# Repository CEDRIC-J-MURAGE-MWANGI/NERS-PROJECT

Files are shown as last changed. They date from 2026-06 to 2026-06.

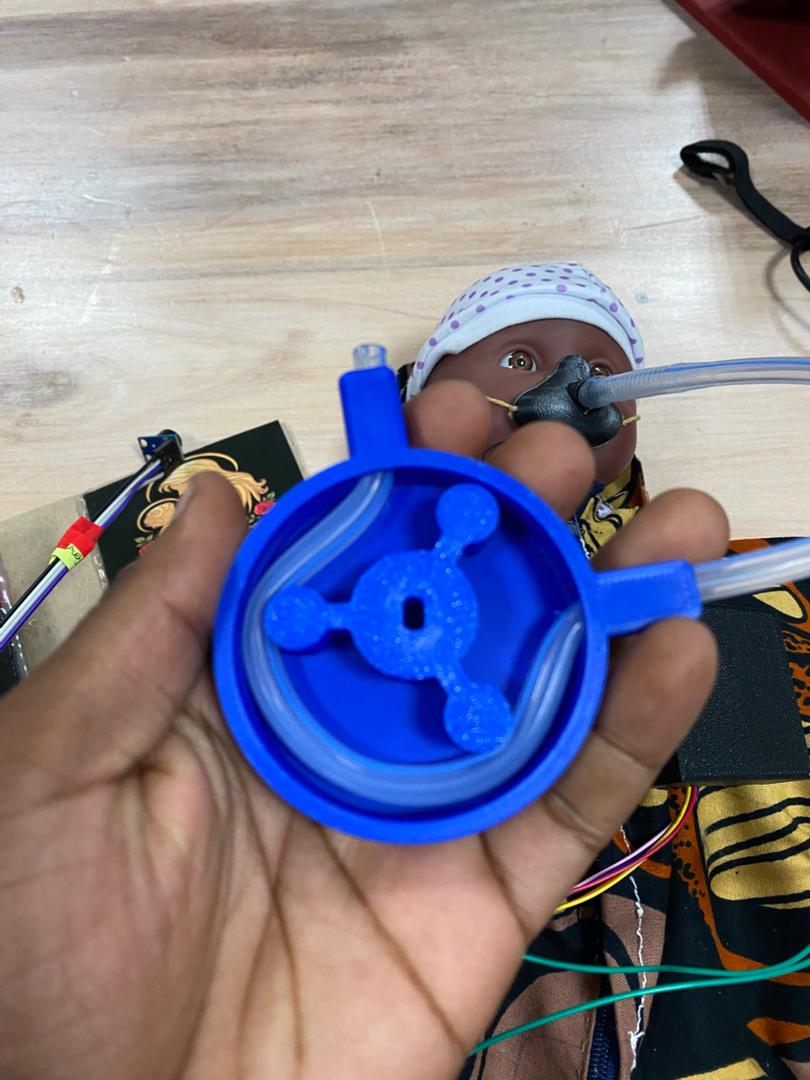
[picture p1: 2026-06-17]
IMAGES/PERISTALTIC PUMP.jpeg

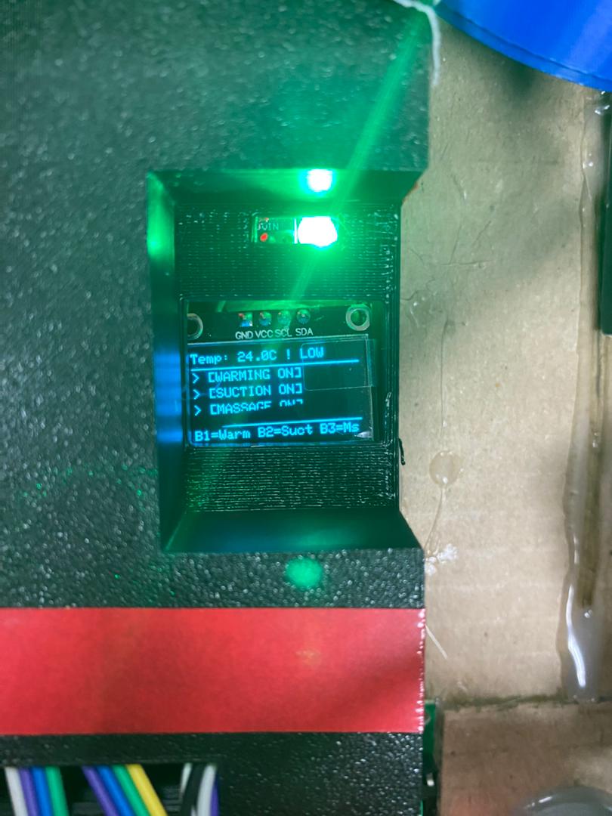
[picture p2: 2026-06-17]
IMAGES/OLED STATUS DISPLAY.jpeg

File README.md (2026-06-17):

# NERS — Neonatal Emergency Response Swaddle

**An integrated, low-cost device for newborn resuscitation in low-resource health facilities.**

> Birth asphyxia is the leading cause of neonatal mortality in Kenya, responsible for 31.6% of all newborn deaths. In the "Golden Minute" after birth, every 30-second delay in starting ventilation raises mortality risk by 16%. NERS exists to remove the delays caused by fragmented equipment during that minute.





---

## Table of Contents
- [Overview](#overview)
- [The Problem](#the-problem)
- [How NERS Works](#how-ners-works)
- [Hardware](#hardware)
- [Firmware](#firmware)
- [Bill of Materials](#bill-of-materials)
- [Results](#results)
- [Repository Structure](#repository-structure)
- [Limitations & Future Work](#limitations--future-work)
- [Team](#team)
- [Acknowledgments](#acknowledgments)
- [References](#references)

---

## Overview

The **Neonatal Emergency Response Swaddle (NERS)** is a single, wearable device that delivers three critical newborn resuscitation interventions simultaneously the moment a non-breathing infant is wrapped in it:

1. **Thermal regulation** — non-contact temperature sensing with embedded warming
2. **Airway clearance** — automated peristaltic suction
3. **Chest stimulation** — rhythmic, bilateral compression

All three modes are independently controlled by an **Arduino Nano V3.0**, activated via labelled push buttons, and monitored in real time on an OLED display. The goal is to eliminate the device-to-device transition time that currently costs lives in under-resourced delivery rooms.

This project was developed through the **Medical Device Innovation Summer Program** at Kenyatta University's **Centre for Design, Innovation & Engineering (CDIE)** lab, in partnership with **Rice 360° Institute for Global Health Technologies**, following a clinical immersion at **Thika Level 5 Hospital**, Kiambu County, Kenya.

A working prototype has been built and validated on a neonatal mannequin, with a total bill of materials cost of **KES 5,937 (~USD 46)**.

## The Problem

In most Kenyan public health facilities, a single birth attendant must manage three separate resuscitation tasks — thermal regulation, airway clearance, and chest stimulation — using three separate, non-integrated pieces of equipment, under acute time pressure and often with limited staff. Each transition between devices costs precious seconds within the Golden Minute.

Key figures motivating this project:
- ~31,000 neonatal deaths in Kenya in 2024 (20.7 per 1,000 live births)
- 16% increase in mortality risk for every 30-second delay in initiating ventilation
- 17.5% of Kenyan neonatal admissions arrive hypothermic, a state linked to a 35% increase in odds of death
- Only 32.7% of Kenyan newborns receive all recommended components of quality neonatal care after birth

NERS targets the fragmentation and operator-dependency at the root of these delays.

## How NERS Works

| Subsystem | Function | Core Components |
|---|---|---|
| **Thermal Regulation** | Continuous non-contact monitoring of neonatal surface temperature with embedded warming | MLX90614ESF IR sensor + heating strip |
| **Airway Clearance** | Controlled negative-pressure suction to clear the airway | 28BYJ-48 stepper motor in a peristaltic pump configuration + silicone tubing |
| **Chest Stimulation** | Rhythmic, bilateral compression replicating the two-thumb encircling technique | Two counter-rotating 28BYJ-48 stepper motors + padded compression elements |
| **Control & Feedback** | Independent mode activation and real-time status display | Arduino Nano V3.0 + 3 push buttons + 0.96" SSD1306 OLED |

Each mode can be activated independently or run concurrently — matching real resuscitation demand, where a birth attendant may need warming, suction, and compression all at once. The temperature sensor (I2C address `0x5A`) and OLED display (I2C address `0x3C`) share a single I2C bus without conflict.

## Hardware

- **Microcontroller:** Arduino Nano V3.0 (ATmega328P)
- **Actuation:** 3× 28BYJ-48 5VDC unipolar stepper motors, each driven via a ULN2003 Darlington driver board
- **Sensing:** MLX90614ESF non-contact infrared thermometer (±0.5°C accuracy, I2C)
- **Display:** 0.96" SSD1306 128×64 OLED (I2C)
- **Input:** 3 debounced push buttons (Warming / Suction / Massage)
- **Suction path:** 3D-printed peristaltic pump head + silicone tubing + neonatal suction catheter
- **Structure:** 3D-printed (PLA) motor mounts and pump housing, integrated into a fabric swaddle

Full pin mapping and component datasheets are documented in the project report (Appendices A & B).

## Firmware

Developed in the Arduino IDE (C/C++) using a cooperative multitasking architecture based on `millis()` timing rather than interrupts:

- **Button polling** with a 300 ms debounce window; each press toggles its mode independently
- **Suction motor** stepped via half-step sequence at 1 ms/step (~0.49 rev/s)
- **Massage motors** counter-rotate (one forward, one reverse) in synchronized steps to produce a squeezing motion
- **Temperature sampling** every 4 seconds, with on-screen alerts (`! LOW` / `OK` / `! HIGH`) based on WHO hypothermia thresholds

**Libraries used:**
- `Wire.h` — I2C communication
- `Adafruit_GFX.h` / `Adafruit_SSD1306.h` — OLED display driver
- `Adafruit_MLX90614.h` — temperature sensor driver

## Bill of Materials

| Component | Qty | Unit Price (KES) | Total (KES) |
|---|---|---|---|
| GY-906 MLX90614ESF IR Temperature Sensor | 1 | 1,500 | 1,500 |
| 28BYJ-48 Stepper Motor 5VDC | 3 | 300 | 900 |
| ULN2003 Stepper Motor Driver Board | 3 | 150 | 450 |
| SSD1306 0.96" I2C OLED Display | 1 | 600 | 600 |
| Arduino Nano V3.0 | 1 | 1,000 | 1,000 |
| Power Supply Adapter 5V 3A | 1 | 600 | 600 |
| Silicone Pipe, Breadboard, Veroboard, Jumper Wires, LEDs, Resistors | — | — | 887 |
| **Total** | | | **5,937 (~USD 46)** |

All components sourced from a single local supplier (PixelElectric, Nairobi), keeping the device locally manufacturable without import dependency.

## Results

All three subsystems were validated independently and concurrently on a neonatal mannequin:

- ✅ Accurate temperature readings and correct alert states across room-temperature and body-temperature ranges
- ✅ Confirmed peristaltic suction wave through silicone tubing with clean activation/deactivation
- ✅ Coordinated, rhythmic bilateral chest compression with no inter-subsystem interference
- ✅ Stable, conflict-free shared I2C bus operation
- ✅ Full concurrent (3-mode) operation validated with no system failure

Full performance tables are available in the project report (Chapter 4).

## Repository Structure

```
.
├── firmware/          # Arduino C/C++ source code
├── hardware/          # Schematics, pin mapping, 3D models (pump head, compression pads, mounts)
├── docs/              # Full project report, grant proposal, datasheets
└── README.md
```
*(Adjust to match your actual repo layout.)*

## Limitations & Future Work

This is a **validated proof of concept**, not yet a clinical device. Current limitations and the planned next steps:

- **Force & pressure calibration** — compression depth and suction pressure are not yet instrumented or calibrated against ILCOR clinical targets
- **Biocompatibility** — PLA and fabric will be replaced with medical-grade silicone for skin contact
- **Custom PCB** — current Veroboard assembly will be replaced with a compact, reliable custom PCB
- **Vital signs monitoring** — future integration of a pulse oximetry module (e.g., MAX30102) for heart rate and SpO₂
- **Clinical validation** — usability studies with real birth attendants, ethical approval, and eventual Kenya Pharmacy and Poisons Board regulatory review

This project has received no prior external funding beyond CDIE program support. A Catalyst Grant application is in progress to fund the calibration and PCB-integration phase as a stage gate toward clinical usability testing.

## Team

| Name | Role | Institution |
|---|---|---|
| **Cedric J. Murage Mwangi** | Hardware & Firmware Lead | Kenyatta University |
| **Hilda Kalino** | Systems & Sustainability Lead | Malawi University of Science and Technology |
| **Keturah Kirabo** | Clinical & Validation Lead | Mbarara University of Science and Technology |

Brought together through the **Medical Device Innovation Summer Program** hosted at Kenyatta University's CDIE lab.

## Acknowledgments

With thanks to the KU CDIE team — Dr. June Madete, Dr. Ken Iloka, Eubrey Mitchy, Stacy Awinja — and interns Antonius Waka and Abigael Njeri, for their support throughout this project. Thanks also to the staff at **Thika Level 5 Hospital** for their hospitality and for allowing the clinical immersion that inspired NERS.

## References

Key sources informing this work include UNICEF and KDHS neonatal mortality data, Mwangi et al. (2018) on time-to-ventilation outcomes, Wainaina et al. (2024) on neonatal hypothermia in Kenya, and the 2023/2025 ILCOR Neonatal Life Support guidelines. Full citations are available in the project report.

---

*For the complete technical writeup, including literature review, methodology, and discussion, see the full project report in this repository.*

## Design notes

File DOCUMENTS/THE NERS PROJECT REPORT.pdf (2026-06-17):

## A NEONATAL EMERGENCY RESPONSE SWADDLE (NERS) FOR NEWBORN RESUSCITATION IN LOW-

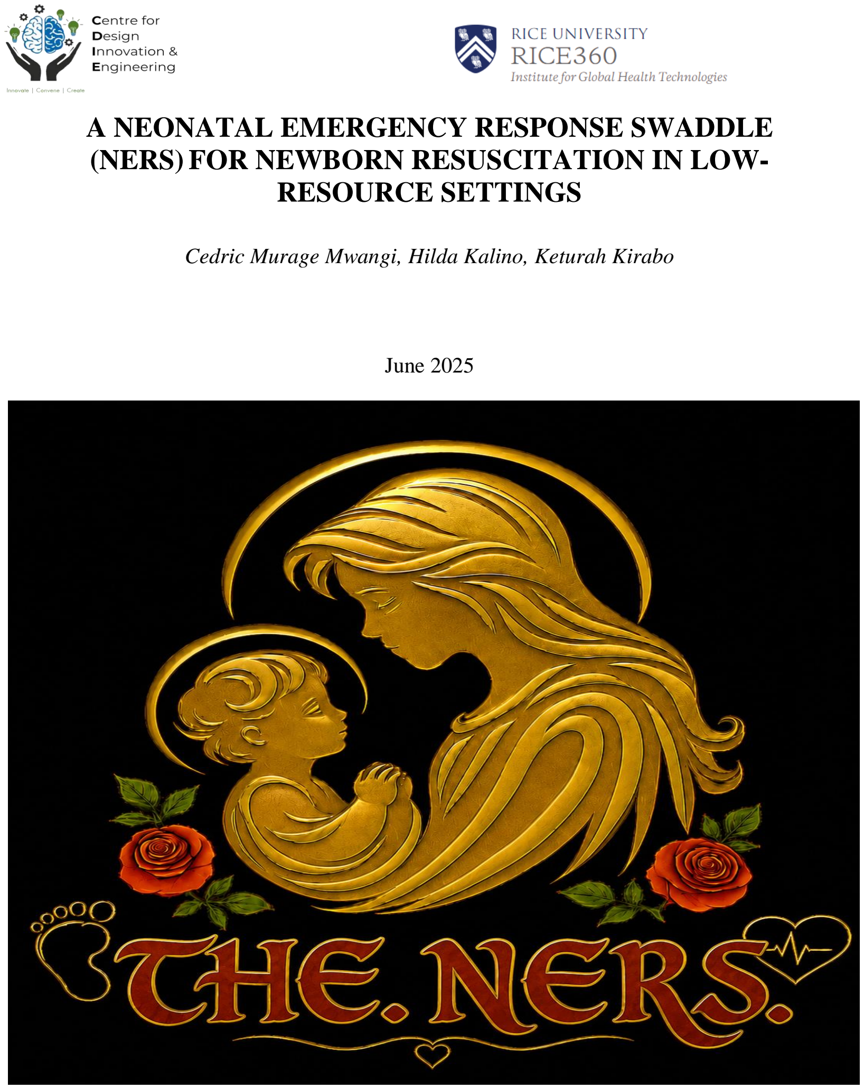
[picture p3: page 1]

## RESOURCE SETTINGS

Cedric Murage Mwangi, Hilda Kalino, Keturah Kirabo

June 2025

Neonatal Emergency Response Swaddle (NERS) — Project Report

## ACKNOWLEDGMENT

We hereby acknowledge the KU CDIE team led by Dr June Madete, Dr Ken Iloka, Eubrey Mitchy, Stacy Awinja, and the interns, Antonius Waka and Abigael Njeri for their great help and support in building this project.

Their support through the Medical Device Innovation summer program hosted at Kenyatta University, was monumental, and this project wouldn’t have been accomplished without them. From the lab sessions, the clinical immersions sessions and the rapid prototyping week.

I would also like to acknowledge the wonderful staff at Thika level 5 hospital, who hosted us and allowed us to interact with them. It was through their hospitality and kindness, that we were able to observe this problem, and thus create the solution via our NERS prototype.

## ABSTRACT

Birth asphyxia is the leading cause of neonatal mortality in Kenya, accounting for 31.6% of all

newborn deaths. Kenya also recorded approximately 31,000 neonatal deaths in 2024 at a rate of

20.7 per 1,000 live births. The critical window for intervention, termed the Golden Minute, is the

sixty seconds following birth during which every 30-second delay in initiating ventilation

increases mortality risk by 16%. In low-resource public health facilities such as Thika Level 5

Hospital, current resuscitation approaches require birth attendants to coordinate three separate

interventions; thermal regulation, airway clearance, and chest stimulation, using three separate

pieces of equipment, under extreme time pressure and often with limited skilled personnel. This

fragmented approach introduces procedural delays that cost lives.

This report presents the design of the Neonatal Emergency Response Swaddle (NERS), a single

integrated device that simultaneously delivers all three primary resuscitation functions to a non-

breathing newborn immediately at birth. The NERS is a swaddle-form device incorporating:

embedded heating strip and an MLX90614ESF infrared temperature sensor for automated thermal

regulation; a 28BYJ-48 stepper motor in a peristaltic pump configuration for controlled airway

suction; and two additional 28BYJ-48 stepper motors with padded compression elements for

rhythmic chest stimulation. All three functions are individually activatable via labelled push

buttons and their status is communicated in real time through a 0.96-inch SSD1306 OLED display.

The system is controlled by an Arduino Nano V3.0 microcontroller and key structural components

are 3D-printed for low-cost, lightweight construction.

The device was designed specifically for the low-resource healthcare context in Kenya, with a total

bill of materials of KES 5,937, making it economically viable for deployment at Level 4 and 5

public facilities. Prototype testing on a neonatal mannequin confirmed correct operation of all three

modes, temperature monitoring with real-time OLED feedback, and stable stepper motor

performance. Future work includes integration of continuous neonatal heart rate monitoring, chest

pad biomechanical optimization, and clinical validation in a simulated delivery room setting.

Keywords: Neonatal resuscitation, birth asphyxia, neonatal emergency, thermal regulation, airway clearance, chest compression, Arduino, low-resource settings, Kenya, biomedical device

## TABLE OF CONTENTS

## Contents

APPENDIX B: PIN MAPPING TABLE — ARDUINO NANO V3.0 | 56
APPENDIX C: GLOSSARY OF CLINICAL TERMS | 57

## LIST OF FIGURES

Figure 1 Arduino nano V3.0 | 23
Figure 2 28BYJ-48 Stepper Motor 5 VDC Unipolar | 24
Figure 3 ULN2003 Stepper Motor Driver Board | 24
Figure 4 MLX90614ESF Non-Contact Infrared Thermometer | 25
Figure 5 0.96" IIC 128x64 OLED Module | 26
Figure 6 Warming strip | 28
Figure 7 Peristaltic suction configuration | 29
Figure 8 Suction Catheter | 30
Figure 9 dual chest stimulation motors | 31
Figure 10 chest stimulation pad against chest wall | 33
Figure 11 Pushbutton configuration | 34
Figure 12 OLED Display Logic | 34
Figure 13 peristaltic pump 3d designs | 36
Figure 14 3D designs of chest stimulation pads | 37
Figure 15 Device Prototype | 43

## LIST OF TABLES

Table 1 Bill of Materials | 37
Table 2 Project Timeline | 38
Table 3 Performance outcomes | 41
Table 4 Comparison with existing technologies | 46
Table 5 Component Specifications | 56
Table 6 PIn mapping table | 56

## ABBREVIATIONS AND ACRONYMS

Abbreviation | Full Form
AHA | American Heart Association
APGAR | Appearance, Pulse, Grimace, Activity, Respiration score
BMV | Bag-and-Mask Ventilation
DHS | Demographic and Health Survey
GPIO | General Purpose Input/Output
ILCOR | International Liaison Committee on Resuscitation
I2C | Inter-Integrated Circuit (communication protocol)
KDHS | Kenya Demographic and Health Survey
KHIS | Kenya Health Information System
LED | Light Emitting Diode
LMIC | Low- and Middle-Income Country
NERS | Neonatal Emergency Response Swaddle
NMR | Neonatal Mortality Rate
NRP | Neonatal Resuscitation Program
OLED | Organic Light-Emitting Diode
PPV | Positive Pressure Ventilation
PVC | Polyvinyl Chloride
SDG | Sustainable Development Goal
SSD | Solomon Systech Display (OLED driver)
UNICEF | United Nations Children's Fund
WHO | World Health Organization

## CHAPTER ONE: INTRODUCTION

### 1.1 Research Background

The first sixty seconds after birth, referred to in neonatal medicine as the Golden Minute, represent

the most critical window in a newborn's extrauterine transition. The vast majority of newborns

make this transition without assistance. However, a significant proportion do not, and when they

fail to breathe, the speed and quality of clinical response in that first minute is the primary

determinant of whether they live, die, or survive with permanent neurological damage.

Birth asphyxia, defined by the World Health Organization as the failure to initiate and sustain

breathing at birth, is the single leading cause of neonatal mortality in Kenya, accounting for 31.6%

of all newborn deaths according to UNICEF [1]. Kenya recorded approximately 31,000 neonatal

deaths in 2024, at a rate of 20.7 per 1,000 live births, a rate that has declined by only 22% since

1990 [2]. This slow progress in neonatal survival is a documented characteristic of the sub-Saharan

African region, where the neonatal mortality rate of 28 per 1,000 live births is significantly above

the global average [3].

The Kenya Demographic and Health Survey (KDHS) 2022 confirmed that neonatal mortality rate

stood at 21 deaths per 1,000 live births, with birth asphyxia, neonatal sepsis, respiratory distress,

and hypothermia identified as the leading causes among preterm and low birth weight infants [4].

Aluvaala et al. (2021), in a multisite retrospective cohort study of 21 Kenyan hospitals,

documented that neonates account for 46% of pediatric admissions but 66% of pediatric deaths, a

stark disproportion that reflects the vulnerability of the newborns [5].

The time-criticality of neonatal resuscitation is quantified in the literature. Evidence from Mwangi

et al. (2018), derived from direct observation of resuscitations at Kakamega County General

Hospital, Kenya, demonstrates that the risk of death increases by 16% for every 30-second delay

in initiating ventilation during the first six minutes following birth [6]. This figure, a 16% increase

in mortality risk for every half-minute of delay, frames the entire engineering challenge that

motivated this project.

Compounding the time-critical nature of the problem, is the multi-task burden placed on the birth

attendant in a low-resource setting. In high-income settings, neonatal resuscitation involves a

trained resuscitation team: one provider manages the airway, one provides chest compressions, one monitors vital signs, and one coordinates. In most Kenyan public hospitals, these tasks fall to

a single nurse or midwife, operating with fragmented equipment under acute pressure.

This reality was directly observed by members of the NERSZ team at Thika Level 5 Hospital,

Kiambu County, Kenya, during a clinical immersion session. A neonate was delivered without

spontaneous breathing. The single birth attendant present had to sequentially: physically transfer

the infant to a resuscitaire; stimulate breathing manually by drying; connect a separate suction

catheter to a wall-mounted suction machine to clear mucus from the airway; and then initiate

manual chest compressions using two fingers on the sternum. Each transition between tasks

consumed time. Time that, by the evidence cited above, directly translates to increased probability

of death or long-term neurological injury.

It was this gap, between the theoretical understanding of what neonatal resuscitation requires and

the practical reality of how it is delivered in under-resourced settings, that this project set out to

address.

### 1.2 Problem Statement

There is a critical absence of integrated, rapid-deployment, affordable neonatal resuscitation

support at the point of delivery in low-resource Kenyan health facilities. Current approaches to

managing birth asphyxia in such settings require birth attendants to simultaneously or sequentially

administer three separate interventions, which are thermal regulation, airway clearance, and chest

stimulation, using three separate pieces of equipment, under conditions of acute clinical pressure,

often with limited or single-person staffing.

This fragmentation introduces measurable procedural delays. Each transition between tasks

represents lost time within the Golden Minute, and as the literature confirms, every 30 seconds of

delay in initiating ventilation increases neonatal mortality risk by 16% [6]. Furthermore, the quality

of manual interventions, particularly chest compressions, is inherently operator-dependent. A 2024

PLOS Global Public Health analysis of the 2022 KDHS found that only 32.7% of Kenyan

newborns receive all recommended components of quality neonatal care after childbirth, a figure

that reflects systemic gaps in the delivery of standardized resuscitation support [7].

Additionally, 17.5% of neonates admitted to 21 study hospitals in Kenya were found to be

hypothermic on admission, with hypothermia associated with a 35% increase in odds of inpatient neonatal death [8]. Heat loss begins immediately after birth when the neonate transitions from the

thermoneutral uterine environment to the ambient room temperature.

The problem is therefore twofold: delays caused by the fragmentation of equipment and tasks; and

the operator-dependency of intervention quality. Both can, in principle, be resolved through

integration and automation. That is precisely what NERS is designed to achieve.

### 1.3 Research Objectives

### 1.3.1 General Objective

To design and develop a Neonatal Emergency Response Swaddle (NERS) that integrates thermal

regulation, airway clearance, and chest stimulation into a single portable device, deployable by a

single birth attendant in under-resourced health facilities at the moment of birth, thereby reducing

procedural delays in neonatal resuscitation.

### 1.3.2 Specific Objectives

- To develop a thermal regulation subsystem using a temperature sensor and embedded heating strips to monitor neonatal body temperature in real time and provide controlled warmth.
- To implement an airway clearance subsystem using a 28BYJ-48 stepper motor in a peristaltic pump configuration with silicon tubing to generate controlled negative pressure for gentle neonatal airway suction.
- To design a chest stimulation subsystem using two 28BYJ-48 stepper motors with padded compression elements to deliver rhythmic, calibrated chest stimulation.
- To validate prototype performance through mannequin testing of all three operational modes, confirming correct mechanical and electronic function prior to any future clinical evaluation.

### 1.4 Justification

This project is justified on clinical, technical, economic, and national health policy grounds.

From a clinical perspective, the consequences of delayed or inadequate neonatal resuscitation are

severe and well-documented. Birth asphyxia survivors who do not receive timely resuscitation

face elevated risks of hypoxic-ischemic encephalopathy (HIE), cerebral palsy, epilepsy, cognitive

impairment, and developmental delay [9]. Effective resuscitation at birth can prevent approximately 30% of birth asphyxia deaths and avert 5–10% of deaths due to complications of

preterm birth [6]. An integrated, single-device approach that eliminates transition delays directly

addresses this mortality burden.

From a technical perspective, the convergence of stepper motor technology, non-contact infrared

sensing, and microcontroller-based embedded systems has created a viable pathway for developing

a working prototype device within a constrained budget. The 28BYJ-48 stepper motor is widely

validated in research prototyping for its precise positional control, low voltage operation (5V), and

compatibility with the Arduino ecosystem via the ULN2003 driver board [10]. The

MLX90614ESF sensor has demonstrated measurement accuracy within ±0.5°C of clinical

reference standards in embedded health monitoring applications [11].

From an economic perspective, the device's total cost of KES 5,937 makes it economically feasible

for procurement by Level 4 and 5 public health facilities in Kenya. The Ministry of Health Kenya's

Newborn and Child Health Strategic Plan 2022–2026 explicitly prioritizes affordable, deployable

innovations for improving neonatal health [12].

From a national health policy alignment perspective, Kenya has committed to reducing neonatal

mortality to at least 12 per 1,000 live births by 2030 in line with the Sustainable Development

Goal (SDG) 3.2 target [13]. With the current NMR at 20.7 per 1,000 live births.

### 1.5 Scope and Limitations

### 1.5.1 Scope

This project encompasses the complete design, development, firmware programming, and

prototype validation of the NERS device. The scope includes:

- Hardware design and assembly: Integration of three 28BYJ-48 stepper motors with their ULN2003 driver boards, one MLX90614ESF temperature sensor, one SSD1306 OLED display module, three push buttons and all necessary power and signal wiring on a Veroboard circuit.
- Mechanical design: 3D-printed motor casing and peristaltic pump configuration for the airway suction subsystem within a swaddle form factor.
- Firmware development: Arduino C/C++ code for the Arduino Nano V3.0 implementing all three operational modes with independent activation, real-time temperature acquisition via the MLX90614 library, stepper motor control using the half-step sequence, debounced button input handling, and OLED display management.
- Prototype validation: Functional testing of all three operational modes on a neonatal mannequin, confirming correct mechanical operation and display feedback.

### 1.5.2 Limitations

This project acknowledges several limitations that define boundaries for future work:

- Clinical validation: The prototype has been tested on a neonatal mannequin only. No clinical trials involving actual neonates have been conducted. Such trials would require ethical approval, biocompatibility certification, and regulatory clearance beyond the scope of this academic project.
- Force calibration: While the stepper motor compression elements provide rhythmic stimulation, precise force calibration against ILCOR-recommended chest compression depths has not been performed. This requires instrumented mechanical testing.
- Suction pressure quantification: The negative pressure generated by the peristaltic pump has not been measured against clinical suction standards. This requires pressure sensor validation.
- Vital signs integration: The current prototype monitors temperature only. It does not include heart rate, oxygen saturation, or respiratory rate monitoring.
- Long-term durability: The prototype has not been subjected to repeated-use endurance testing, sterilization cycle testing, or ingress protection assessment.

## CHAPTER TWO: LITERATURE REVIEW

### 2.1 Introduction

This chapter presents a comprehensive review of the existing literature relevant to the NERS

project, covering the epidemiology of neonatal mortality and birth asphyxia in Kenya and sub-

Saharan Africa.

### 2.2 Neonatal Mortality in Kenya and Sub-Saharan Africa

### 2.2.1 Regional and Global Context

The global neonatal mortality rate stands at approximately 18 deaths per 1,000 live births, with

sub-Saharan Africa carrying a disproportionate burden of 28 deaths per 1,000 live births, which is

more than 1.5 times the global average [3]. Globally, prematurity, birth asphyxia, and neonatal

sepsis account for close to eight in ten neonatal deaths, with this burden concentrated

overwhelmingly in low- and middle-income countries [2]. The International Liaison Committee

on Resuscitation (ILCOR) has identified that timely, effective resuscitation immediately at birth

is among the highest-impact interventions available to reduce neonatal mortality in resource-

limited settings [14].

The Lancet Global Health (2023) published an ILCOR statement noting that most

recommendations on cardiopulmonary resuscitation have been developed from the perspective of

high-resource settings, with insufficient adaptation to the specific constraints of low-resource

environments, which includes limited staffing, fragmented equipment, and absence of

resuscitation teams [15]. This represents a documented gap in global neonatal resuscitation policy

that directly motivates the design philosophy of NERS.

### 2.2.2 Kenya-Specific Epidemiology

The 2022 KDHS confirmed a neonatal mortality rate of 21 deaths per 1,000 live births, with no

statistically significant change from the 2014 rate of 22 per 1,000 [4]. By 2024, Kenya's absolute

number of neonatal deaths had risen to approximately 31,000 annually due to population growth,

even as the rate per 1,000 live births declined marginally to 20.7 [2].

Data from the Kenya Health Information System confirms that over 70% of neonatal deaths are

attributable to three causes: prematurity, birth asphyxia, and neonatal sepsis [17]. These three causes are also the primary conditions driving Kenya's disproportionate pediatric hospital

mortality: Aluvaala et al. (2021) documented that neonates constitute 46% of pediatric admissions

but 66% of pediatric deaths across 21 Kenyan hospitals [5].

The 2022 KDHS also revealed stark geographic and socioeconomic disparities. Only 31% of

deliveries in the poorest households had a skilled attendant at birth, compared to 93% in the richest

households [1]. This disparity in skilled attendance, directly correlated with the ability to recognize

and manage birth asphyxia, shows the urgency of developing devices that aid the birth attendants

in resource-constrained settings.

Moreover, a 2024 analysis of the 2022 KDHS by Asiimwe et al. found that only 32.7% of Kenyan

newborns received all recommended components of quality neonatal care after childbirth [7]. This

figure quantifies the scale of the systems gap that an integrated device like NERS is designed to

address at the point of delivery.

### 2.3 Birth Asphyxia: Pathophysiology and Clinical Significance

### 2.3.1 Definition and Incidence

Birth asphyxia is defined by the WHO as the failure to initiate and sustain breathing at birth. It is

estimated that approximately 10 million babies globally experience breathing difficulties at birth

annually [3]. Approximately 700,000 newborns die from birth complications each year, with an

estimated 233,000 surviving with moderate-to-severe neurodevelopmental impairment [3]. In

Kenya, birth asphyxia accounts for 29–31.6% of neonatal deaths, making it the single leading

cause [1, 5].

### 2.3.2 Pathophysiology

When a neonate fails to breathe at birth, the sequence of pathophysiological events is rapid and

predictable. Primary apnea which is characterized by cessation of respiratory effort in response to

hypoxic stress, is followed by gasping respirations. If oxygenation is not restored, secondary apnea

develops, which is a deeper, more refractory cessation of breathing that does not respond to

stimulation alone and requires positive pressure ventilation. The transition from primary to

secondary apnea can occur within minutes, and the ability of birth attendants to distinguish

between these states in real-time is limited without monitoring equipment [14].

Accompanying respiratory failure, hypoxia drives progressive bradycardia and ultimately cardiac

arrest. The neonatal myocardium is relatively tolerant of hypoxia compared to the adult, but

sustained oxygen deprivation above approximately 5–8 minutes results in irreversible myocardial

and cerebral injury. The neurological consequences include hypoxic-ischemic encephalopathy

(HIE), which in its severe form is associated with cerebral palsy, epilepsy, cognitive impairment,

and sensory deficits [9].

### 2.3.3 The Golden Minute and Time-to-Ventilation

A direct observation study by Mwangi et al. (2018) at Kakamega County General Hospital, Kenya,

established that the risk of death increases by 16% for every 30-second delay in initiating

ventilation up to six minutes, and by 6% for each additional minute of delay in applying bag-and-

mask ventilation [6]. This finding provides the quantitative basis for the engineering requirement,

which is any integrated resuscitation device must be deployable within seconds of birth, not

minutes.

The American Heart Association (AHA) and American Academy of Pediatrics 2023 reaffirmed

that the first 60 seconds after birth are the highest-impact intervention window and that delays in

initial assessment and intervention are directly correlated with adverse outcomes [18]. The 2025

ILCOR Neonatal Life Support Consensus on Science with Treatment Recommendations further

emphasizes that the structure and speed of the initial response are critical determinants of the

outcome of the newborn [19].

### 2.4 Neonatal Hypothermia

### 2.4.1 Definition, Prevalence, and Mortality Association

The WHO defines neonatal hypothermia as an axillary temperature below 36.5°C in newborns

within the first 28 days of life. It is stratified as mild (36.0°C–36.4°C), moderate (32.0°C–35.9°C),

and severe (<32.0°C) [20]. Hypothermia is a major contributor to neonatal mortality, acting both

as a primary cause of death and as a comorbidity that amplifies the severity of other conditions

including birth asphyxia and sepsis.

Wainaina et al. (2024), in a study across 21 neonatal units in Kenya analyzing 58,804 newborns,

found that 17.5% arrived hypothermic on admission. The study found that hypothermia at

admission was associated with a 35% increase in the odds of neonatal inpatient death. Significant associations were found between low birth weight, very low APGAR scores, and hypothermia at

admission [8]. This study directly informs the thermal regulation design requirements of NERS.

### 2.4.2 Heat Loss Mechanisms in the Newborn

Newborns are particularly vulnerable to heat loss because of their high surface-area-to-volume

ratio, limited subcutaneous fat insulation, immature thermoregulatory mechanisms, and wet skin

at birth which dramatically increases evaporative heat loss. The transition from the thermoneutral

uterine environment (approximately 37°C) to the ambient delivery room temperature (typically

22–26°C) creates an immediate thermal gradient across which the neonate loses heat [20].

Without active warming from radiant warmers, heated mattresses, skin-to-skin contact, or

integrated warming elements, a neonate can develop hypothermia within minutes. Kyokan et al.

(2023), reviewing warming devices for neonates in low-resource settings, confirmed that

integrated thermal management remains a critical, underprovided component of neonatal

resuscitation in facilities where radiant warmers and incubators are unavailable or non-functional

[21].

### 2.4.3 Temperature Monitoring Requirements

Continuous, non-contact temperature monitoring is the clinical standard in neonatal intensive care.

The MLX90614ESF infrared thermopile sensor achieves non-contact temperature measurement

with factory-calibrated accuracy of ±0.5°C and a 17-bit resolution (0.02°C), communicating via

I2C protocol. In embedded health monitoring applications using this sensor with an Arduino Nano,

temperature differences smaller than ±0.2°C from clinical reference thermometers have been

reported [11]. The non-contact mode of measurement is clinically advantageous as it eliminates

the need for sensor contact with delicate neonatal skin, which is important in a resuscitation context

where skin integrity may be compromised.

### 2.5 Airway Clearance in Neonatal Resuscitation

### 2.5.1 Clinical Rationale

Upper airway obstruction due to amniotic fluid, mucus, and debris is a major contributor to

respiratory failure in neonates who do not breathe spontaneously at birth. In the clinical scenario

observed at Thika Level 5 Hospital, airway clearance via suction was a necessary early step in the resuscitation sequence. Without a clear airway, all subsequent respiratory interventions are

ineffective.

Current WHO guidelines and ILCOR recommendations support airway clearance as part of the

initial stabilization steps for a neonate who fails to establish spontaneous breathing, though they

note that routine suctioning in vigorous newborns is not recommended. For non-vigorous

newborns with obvious airway obstruction, the target population for NERS, gentle suction is

recommended [18, 19].

### 2.5.2 Peristaltic Pump Mechanism

Peristaltic pumps generate fluid flow by the sequential compression of a flexible tube by rollers

mounted on a rotating head. The compression-relaxation cycle creates a travelling wave of

negative pressure that draws fluid through the tube from the inlet to the outlet. This mechanism is

preferred in medical applications because the fluid contacts only the inner surface of the tubing,

eliminating cross-contamination risk with the pump mechanism.

The 28BYJ-48 stepper motor, has been demonstrated to drive peristaltic pump configurations at

flow rates suitable for airway clearing applications [10]. Its precise, controllable rotation enables

the birth attendant or the firmware to regulate suction intensity by adjusting motor speed. The 3D-

printed pump head that compresses the silicone tubing can be fabricated to the tolerances required

for consistent compression depth, ensuring predictable suction generation.

### 2.6 Chest Compression in Neonatal Resuscitation

### 2.6.1 Clinical Guidelines

Current ILCOR and AHA/AAP neonatal resuscitation guidelines recommend initiating chest

compressions when the heart rate remains below 60 beats per minute despite adequate ventilation

[18, 19]. The recommended technique is the two-thumb/encircling-hands method, which

consistently achieves greater compression depth, less provider fatigue, and higher accuracy than

the two-finger technique based on a 2023 ILCOR scoping review of 29 randomized crossover

manikin studies [22].

The recommended compression depth is approximately one-third of the anterior-posterior

diameter of the neonatal chest. For a typical term neonate with an AP diameter of approximately

7–8 cm, this corresponds to a compression depth of approximately 2.3–2.6 cm. The recommended

compression rate is 90 compressions per minute, coordinated with a 3:1 compression-to-

ventilation ratio [19]. A 2022 randomized controlled animal trial by Bruckner et al. comparing

compression rates of 90 versus 180 per minute in asphyxiated newborn piglets provided additional

evidence supporting the established 90/min rate as physiologically appropriate [23].

### 2.6.2 Consistency Challenges in Manual Compression

Despite clear guidelines, achieving consistent chest compression quality under emergency

conditions is a documented challenge. A single provider managing both airway and compressions,

which is the standard of care in most rural Kenyan delivery rooms, cannot maintain consistent

depth, rate, and full chest recoil over time. Provider fatigue, the difficulty of maintaining accurate

hand positioning while managing other tasks, and the cognitive load of counting under pressure

all reduce compression quality.

Automated compression devices have been developed and validated for adult and pediatric

resuscitation to address exactly this problem. For neonates, the concept of an automated

compression assistance device is less developed but has been explored in research settings,

including the BabySaver platform evaluated in Uganda (2025) which demonstrated significantly

shorter time to successful resuscitation compared to standard care, along with higher APGAR

scores and reduced neonatal morbidity [24]. NERS builds on this conceptual framework at lower

cost and in an integrated swaddle form.

### 2.7 Existing Technologies and Device Landscape

### 2.7.1 Standard Resuscitation Equipment

Standard equipment at a typical Kenyan Level 5 delivery room for neonatal resuscitation includes:

a resuscitaire (radiant warmer with work surface), a bag-valve-mask device for positive pressure

ventilation, a wall-mounted suction unit with suction catheter, and a stethoscope. In better-

resourced facilities, a pulse oximeter may be available. This equipment requires the birth attendant

to be physically mobile between devices, managing each function sequentially or with assistance.

The critical limitation is not the absence of individual technologies, but the absence of integration.

No single device currently available for the Kenyan Level 4/5 facility context combines thermal regulation, airway clearance, and chest stimulation in a form factor deployable by a single provider

at the point of delivery without requiring the infant to be transferred between stations.

### 2.7.2 Commercially Available Integrated Devices

The BabySaver device is a purpose-built bedside resuscitation platform designed for low-resource

settings, providing a firm surface for resuscitation, cord clamp capability, bag-valve-mask holder,

and basic monitoring. A 2025 pre-post implementation study at Mbale Hospital, Uganda, found

that its deployment in combination with the NeoBeat neonatal heart rate monitor significantly

improved resuscitation outcomes by increasing bedside resuscitation rates from 9.3% to 45.3%

and reducing time to successful resuscitation from 8 minutes to 5 minutes [24]. However, the

BabySaver does not integrate automated chest compression or airway suction, and it is expensive.

### 2.7.3 Research Prototypes

A 2024 review article in ScienceDirect on simulation-based neonatal resuscitation training in low-

resource settings noted the critical gap between training quality and device availability. It was

identified that even when providers are trained in resuscitation, the absence of integrated

equipment at the point of delivery undermines the effectiveness of that training [25]. This aligns

directly with the design motivation for NERS, where a trained provider should not have to

compensate for equipment fragmentation.

Research into neonatal vital sign monitoring wearables, including the NeoWarm device (2025),

which integrates MAX30102 pulse oximetry, MLX90614 temperature sensing, and ECG via an

AD8232 frontend on a Bluetooth SoC for neonatal monitoring during kangaroo care, demonstrates

the technical viability of such sensors in neonatal healthcare [26]. The NERS project builds on this

technical landscape but orients toward active resuscitation rather than monitoring.

### 2.8 Thermal Sensing Technologies

The MLX90614ESF infrared non-contact thermometer uses a thermopile detector to measure

thermal radiation emitted from the surface of an object, providing temperature measurement

without physical contact. It operates on the Stefan-Boltzmann principle which states that every

object above absolute zero emits thermal radiation proportional to the fourth power of its absolute

temperature. The thermopile sensor converts this radiation into a measurable voltage, which is processed by the sensor's onboard signal chain and outputted as a calibrated temperature value via

I2C.

Key specifications relevant to the NERS application include: measurement range of -70°C to

+382°C (object) and -40°C to +125°C (ambient); factory calibration accuracy of ±0.5°C in the

body temperature range; 17-bit ADC resolution providing 0.02°C minimum detectable

temperature difference; and I2C communication at up to 400 kHz [27]. The GY-906 module form

factor of this sensor provides 5V-compatible operation via an on-board 3.3V regulator, making it

directly compatible with the Arduino Nano's 5V supply rail.

Non-contact infrared thermometry has been validated in neonatal clinical contexts as an accurate

and practical alternative to contact-based axillary and rectal thermometry, with the additional

advantage of not requiring probe insertion or skin contact that could be uncomfortable or harmful

in a neonate undergoing resuscitation [21].

### 2.9 Integrated Neonatal Resuscitation Devices: Research Landscape

The concept of an integrated, portable neonatal resuscitation device has gained increasing attention

in biomedical engineering literature, particularly following the renewed focus on reducing

neonatal mortality in LMICs under the SDG framework. Schmolzer et al. and the ILCOR NLS

Task Force have highlighted that feedback CPR devices for neonatal cardiac arrest are an emerging

area requiring further development [19].

The particular innovation of NERS is the swaddle form factor, which enables simultaneous

positioning of all three resuscitation modalities on the neonate's body at the moment of birth,

eliminating the need for the birth attendant to transfer the infant between devices or to hold sensors

and actuators in position manually. This form factor innovation, combined with the price point

below USD 50, represents a novel contribution to the design landscape for integrated neonatal

resuscitation support in low-resource settings.

## CHAPTER THREE: METHODOLOGY

### 3.1 Introduction

This chapter describes the methodology employed in designing, developing, and testing the NERS

prototype. It covers the engineering design philosophy, system architecture, component selection

rationale, detailed subsystem design for thermal regulation, airway clearance, and chest

stimulation, firmware architecture, mechanical and physical design, budget, and project timeline.

### 3.2 Design Philosophy and Engineering Approach

The NERS device was designed around three core engineering principles derived directly from the

clinical problem identified at Thika Level 5 Hospital:

- Integration: All three primary resuscitation interventions, including thermal regulation, airway clearance, and chest stimulation which are embedded in a single device. The birth attendant applies one device, not three. This eliminates device-to-device transition time and reduces cognitive load.
- Simplicity of Operation: The device must be operable by a single trained birth attendant under acute emergency conditions. The user interface is therefore reduced to three labelled push buttons and one OLED display.
- Affordability and Deplorability: The device must be manufacturable within the budget constraints of a low-resource facility and using components available in the Kenyan market. The total bill of materials was constrained to below KES 6,000 , and all components were sourced from a single Kenyan supplier (PixelElectric, Nairobi).

The engineering approach followed a rapid iterative prototyping cycle consistent with the

compressed project timeline.

### 3.3 System Architecture Overview

The NERS system is organized into four functional layers:

- Sensing Layer: The MLX90614ESF infrared temperature sensor provides real-time, non-contact measurement of the neonate's surface temperature at a 4-second update interval. This layer provides the feedback for the thermal regulation subsystem.
- Control Layer: The Arduino Nano V3.0 serves as the central processing unit. It receives temperature data from the sensing layer, reads button inputs from the user interface layer, drives the stepper motors in the actuation layer, and manages the display and indicator outputs.
- Actuation Layer: Three 28BYJ-48 stepper motors provide the mechanical work of the device. Motor 3 (suction motor) drives the peristaltic pump for airway clearance. Motors 1 and 2 (left and right motors) provide bilateral chest compression stimulation. Heating elements embedded in the swaddle fabric provide thermal regulation.
- User Interface Layer: The SSD1306 0.96-inch OLED display provides real-time temperature readout and active mode indication. Three push buttons (BTN1: Warming; BTN2: Suction; BTN3: Massage) enable independent mode activation.

### 3.4 Component Selection and Rationale

### 3.4.1 Arduino Nano V3.0 — Microcontroller

The Arduino Nano V3.0 was selected as the central microcontroller for several reasons. Its

ATmega328P processor provides 14 digital I/O pins and 8 analog input pins, sufficient to

accommodate the 12 stepper motor control pins (4 per motor x 3 motors), 3 button input pins, 1

heating strip pin, and I2C bus shared by the temperature sensor and OLED display. The Arduino's

5V operating voltage is directly compatible with all selected components. The Arduino IDE with

its extensive library ecosystem, including the Adafruit MLX90614 and Adafruit SSD1306

libraries, enabled rapid firmware development within the project timeline.

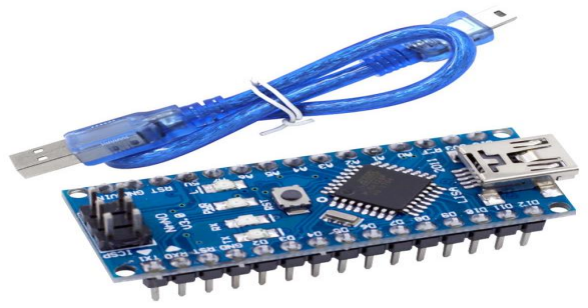
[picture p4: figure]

Figure 1 Arduino nano V3.0

3.4.2 28BYJ-48 Stepper Motor — Actuation

The 28BYJ-48 5VDC unipolar stepper motor was selected for all three actuation functions. Its

specifications are directly relevant to the NERS requirements. It has 32 internal steps per

revolution with a 1:64 gear reduction providing 2048 effective steps per revolution for precise positional control. Moreover its 5VDC operating voltage matches the Arduino supply, and 240

mA rated current per phase, is within the ULN2003A driver board's capability. Additionally, its

dimensions of 28mm diameter x 19mm depth, is compact enough for swaddle integration.

At KES 300 per motor, three motors cost less than USD 7, which is a fraction of the cost of any

clinical actuator. The motor's compatibility with the half-step drive sequence implemented in

firmware produces smooth rotation necessary for peristaltic pump operation and rhythmic

compression delivery.

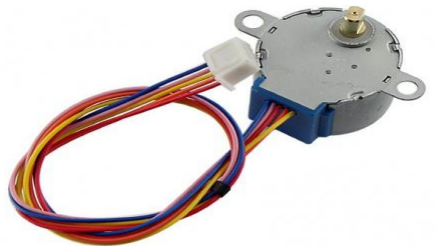
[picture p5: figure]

Figure 2 28BYJ-48 Stepper Motor 5 VDC Unipolar

### 3.4.3 ULN2003 Stepper Motor Driver Board

The ULN2003A Darlington transistor array driver board provides the current amplification

required to drive the 28BYJ-48 motor coils from the Arduino's 5V GPIO pins, which cannot supply

sufficient current directly. Each ULN2003 board drives one motor, providing 500 mA per channel,

which is more than adequate for the 240 mA motor rating, with flyback diodes integrated for back-

EMF protection. At KES 150 per board, three driver boards total KES 450, contributing minimally

to the overall budget.

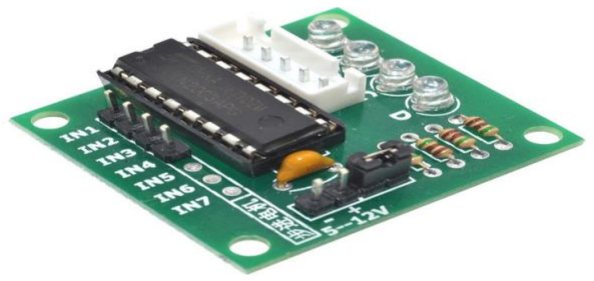
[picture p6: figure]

Figure 3 ULN2003 Stepper Motor Driver Board

### 3.4.4 MLX90614ESF — Temperature Sensing

The MLX90614ESF was selected for its non-contact operation, I2C interface, and accuracy within

the clinically relevant neonatal temperature range of 32°C–38°C. Its factory-calibrated accuracy

of ±0.5°C and resolution of 0.02°C provide the measurement precision required to distinguish

normal neonatal temperature of 36.5°C–37.5°C, from mild hypothermia (36.0°C–36.4°C) and

from low-grade fever (>37.5°C), which are the critical alert thresholds for the NERS warming

subsystem. The I2C interface shares the bus with the OLED display, reducing wiring complexity.

At KES 1,500 per unit, it is the most expensive single component in the bill of materials, but no

lower-cost alternative provides equivalent accuracy and non-contact operation [27].

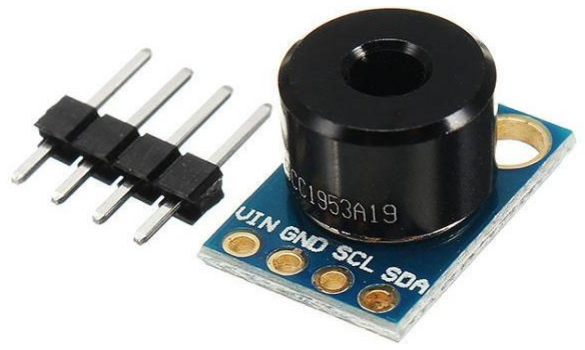
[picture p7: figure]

Figure 4 MLX90614ESF Non-Contact Infrared Thermometer

### 3.4.5 SSD1306 OLED Display

The 0.96-inch SSD1306 OLED display provides 128x64 pixel resolution with I2C communication

at 400 kHz. The OLED technology provides high contrast and wide viewing angles without

requiring a backlight, making it readable under the variable lighting conditions of a delivery room.

The display is used to show current temperature reading and status (when warming mode is active);

active mode indicators ('[WARMING ON]', '[SUCTION ON]', '[MASSAGE ON]'); and button

options. The Adafruit SSD1306 library provides a comprehensive graphics API enabling text

rendering at multiple sizes and line drawing.

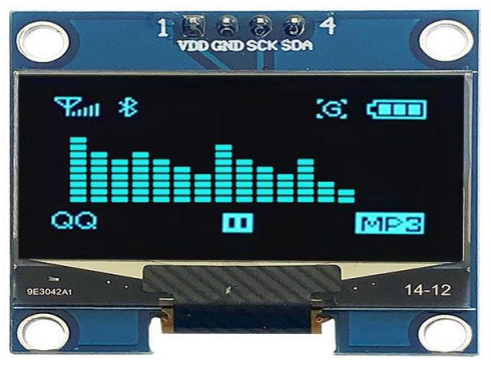
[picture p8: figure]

Figure 5 0.96" IIC 128x64 OLED Module

### 3.4.6 Silicone Pipe — Suction Tubing

Silicone pipe was selected for the peristaltic pump tubing due to its flexibility, chemical inertness,

transparency enabling visual confirmation of fluid movement, and compatibility with the

compression forces generated by the 28BYJ-48 motor-driven pump head.

### 3.5 Thermal Regulation Subsystem Design

### 3.5.1 Design Requirements

The thermal regulation subsystem must:

1. Continuously monitor neonatal surface temperature without skin contact.
2. Provide controlled warmth to prevent hypothermia.
3. Alert the birth attendant when temperature is outside the safe range.
4. Display current temperature in real time on the OLED.

### 3.5.2 Sensor Configuration

The MLX90614ESF sensor is mounted in the swaddle fabric with its optical window oriented

toward the neonate's skin, positioned to measure thoracic surface temperature without contact. The

sensor communicates via I2C to the Arduino Nano. The Adafruit_MLX90614 library initializes

the sensor and reads object temperature in Celsius.

The firmware reads temperature every 4 seconds, triggered by a time-based condition in the main

loop. This sampling interval was selected to provide sufficiently frequent updates to detect

temperature trends while minimizing I2C bus activity. The temperature value is stored as a float

variable and displayed on the OLED with one decimal place precision.

### 3.5.3 Temperature Alert Logic

The firmware implements a threshold-based alert system. If the temperature reading falls below

36.0°C, the OLED displays '! LOW' adjacent to the temperature value. If above 37.5°C, it displays

'! HIGH'. When within range, 'OK' is displayed. The threshold of 36.0°C corresponds to the WHO

definition of the mild/moderate hypothermia boundary, below which active warming intervention

escalation is required [20]. The threshold of 37.5°C provides a fever alert threshold appropriate

for the immediate newborn period.

### 3.5.4 Heating Elements

The thermal regulation subsystem includes heating elements embedded within the swaddle fabric.

These provide radiant warmth to the neonate's body surface, preventing the evaporative, radiative,

and conductive heat losses that occur immediately following birth. The heating elements are

activated when Mode 1 (Warming) is enabled via BTN1, toggling the warmingOn flag. In the

current prototype, a red LED is activated as a visible indicator when warming mode is on,

confirming to the birth attendant that the warming subsystem is active. The OLED displays a 'Baby

Warming' confirmation screen for 3 seconds on mode activation before returning to the main home

screen.

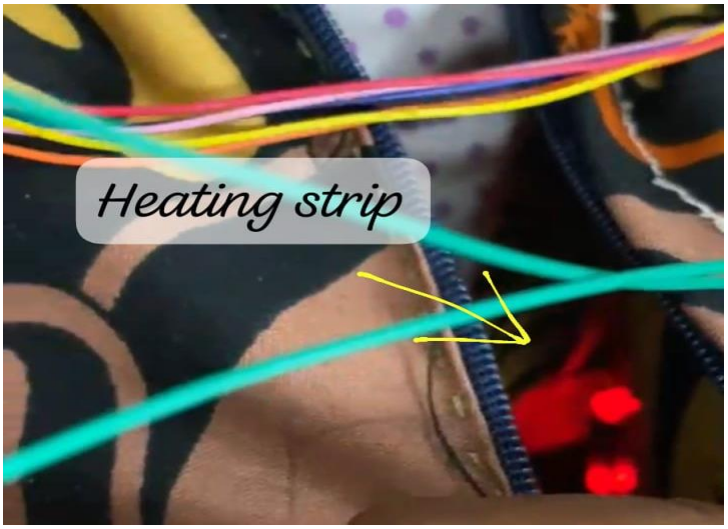
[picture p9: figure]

Figure 6 Warming strip

### 3.6 Airway Clearance Subsystem Design

### 3.6.1 Design Requirements

The airway clearance subsystem must:

1. Generate controlled negative pressure at the distal end of a suction catheter.
2. Produce suction that is gentle and controllable, sufficient to remove mucus and fluid from

the neonatal airway but not so forceful as to cause airway trauma.

3. Be activatable by a single button press.
4. Operate continuously once activated until the attendant deactivates it.

### 3.6.2 Peristaltic Pump Configuration

The suction motor which is a 28BYJ-48 stepper motor, controlled via ULN2003 driver board,

drives a 3D-printed peristaltic pump head that compresses the silicone tubing. The pump head consists of a rotor with three rollers positioned to compress the tubing against a curved backing

surface. As the rotor turns, each roller compresses and releases a segment of tubing in sequence,

generating a travelling compression wave that creates negative pressure behind each roller and

positive pressure ahead of it. The inlet side of the tubing is connected to the suction catheter, as

the outlet side directs collected fluid to a collection reservoir.

The firmware drives the suction motor using the half-step sequence, advancing one step every

SUCTION_STEP_MS milliseconds (1 ms per step). This produces a step rate of 1,000 steps per

second, corresponding to approximately 0.49 revolutions per second of the motor shaft (2048

steps/rev at 1ms/step).

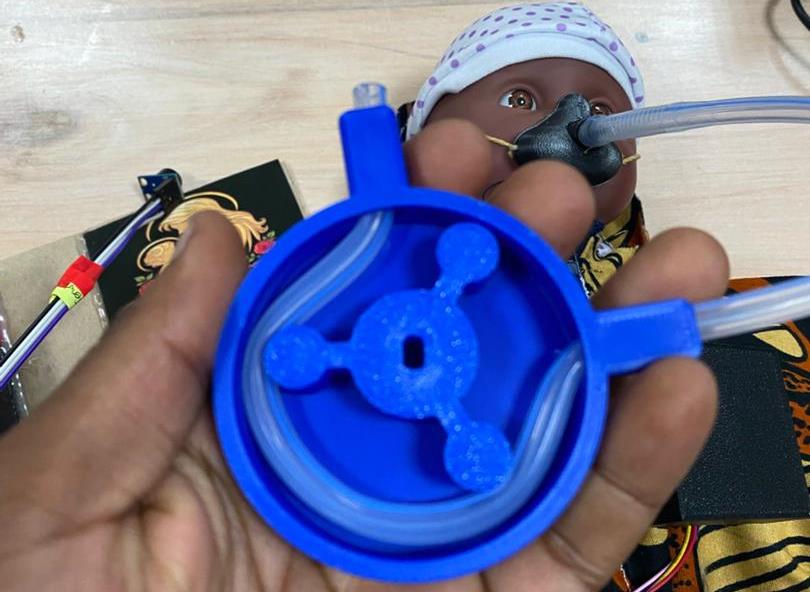
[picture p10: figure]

Figure 7 Peristaltic suction configuration

### 3.6.3 Catheter Interface

In the prototype, a neonatal suction catheter can be connected to the inlet end of the silicone

tubing. The silicone tube accommodates the compression forces of the pump head while maintaining adequate flexibility for catheter positioning by the birth attendant. In a clinical

implementation, the suction catheter would be sterile and single-use, and the silicone tubing

connecting the catheter to the pump would be also autoclavable or also single-use.

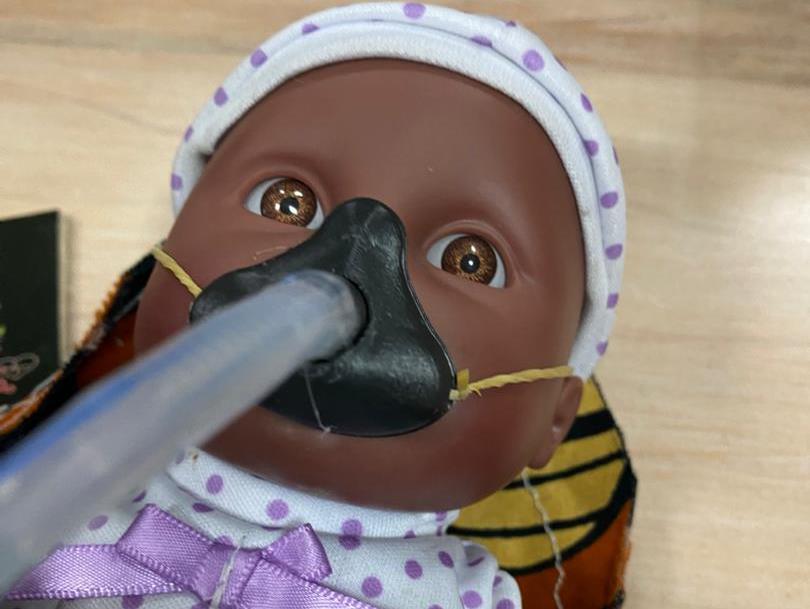
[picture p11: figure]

Figure 8 Suction Catheter

### 3.7 Chest Stimulation Subsystem Design

### 3.7.1 Design Requirements

The chest stimulation subsystem must:

1. Deliver rhythmic, bilateral compression stimulation to the neonatal sternum and lower

chest.

2. Operate at a rate consistent with ILCOR neonatal resuscitation guidelines (approximately

90 compressions per minute).

3. Provide controlled, reproducible compression depth.
4. Be activatable by a single button press while the birth attendant maintains other

interventions.

### 3.7.2 Dual Motor Configuration

Two stepper motors via their respective ULN2003 driver boards drive bilateral padded

compression elements positioned on either side of the neonatal sternum. The use of bilateral

elements distributes compression force symmetrically, reducing the risk of rib stress concentration

associated with unilateral point-force compression, while maintaining the two-thumb encircling

principle recommended by ILCOR [22].

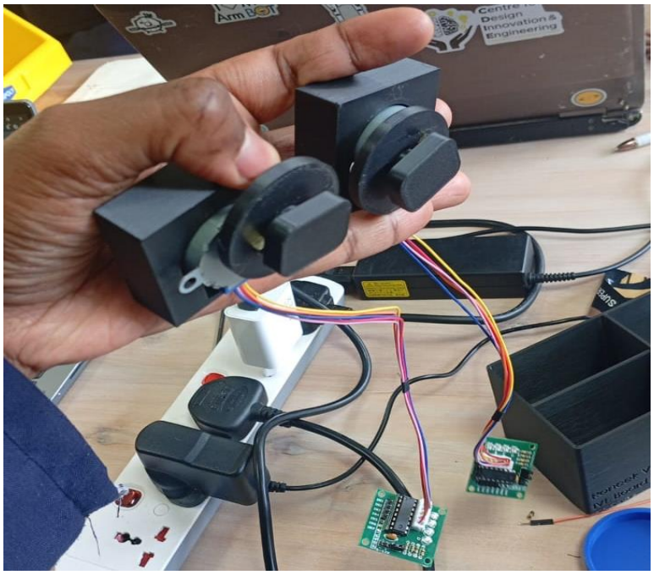
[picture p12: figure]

Figure 9 dual chest stimulation motors

### 3.7.3 Counter-Rotation Mechanism

The firmware implements a counter-rotation mechanism for the two massage motors to generate a

coordinated compressive motion. The left motor steps backward while the right motor steps

forward simultaneously, on each cycle of the massage. This counter-rotation causes the two

compression elements to move toward each other on the compression stroke and away from each

other on the release stroke, producing a squeezing action representative of the two-thumb

encircling technique.

Both motors advance one step every MASSAGE_STEP_MS milliseconds (1 ms per step),

producing the same rotational rate as the suction motor. The compression frequency, the number

of full compression-release cycles per minute, is determined by the mechanical geometry of the

compression element attachment to the motor shaft, which in the current prototype is set by the

physical cam.

### 3.7.4 Compression Pads

The compression elements consist of padded contacts positioned against the neonatal chest wall

within the swaddle fabric. The padding material is selected to provide compliance, distributing

contact force over an area rather than a point, while maintaining sufficient firmness to transmit the

motor's rotational force as a translational compression. In the prototype, PLA padding is used. In

a clinical device, medical-grade silicone padding optimized for neonatal anatomy would be used.

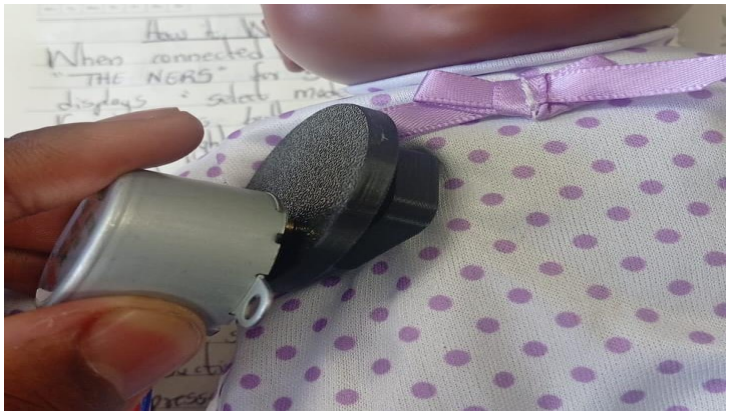
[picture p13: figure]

Figure 10 chest stimulation pad against chest wall

### 3.8 User Interface Design

### 3.8.1 Push Button Interface

Three push buttons are connected to Arduino analog pins and configured as digital inputs with

INPUT_PULLUP, corresponding to Mode 1 (BTN1: Warming), Mode 2 (BTN2: Suction), and

Mode 3 (BTN3: Massage). Each button toggles its respective mode flag (warmingOn, suctionOn,

massageOn) independently when pressed, enabling any combination of modes to be active

simultaneously, which is the expected clinical use case, where all three functions may be needed

concurrently.

Button debouncing is implemented in firmware with a 300 ms debounce window, preventing false

triggering from contact bounce. The firmware waits for the button to be released before registering

the press, preventing accidental hold-activation.

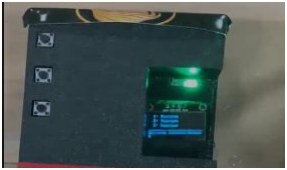
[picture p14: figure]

Figure 11 Pushbutton configuration

### 3.8.2 OLED Display Logic

The OLED display is managed by the drawHome() function, which renders the current state of all

three modes and when warming mode is active , the current temperature reading. The display

layout is as follows: when warming is active, the top row shows the temperature reading and status

('Temp: 36.8C OK' or with alert flags); below, all three mode status lines are shown, with active

modes prefixed by '> [MODE ON]' and a bottom divider line shows button options ('B1=Warm

B2=Suct B3=Msg').

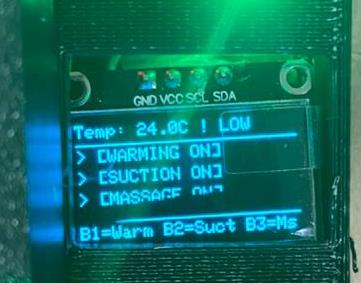
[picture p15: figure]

Figure 12 OLED Display Logic

### 3.9 Firmware Architecture

### 3.9.1 Development Environment

Firmware was developed in the Arduino IDE using C/C++ with the Arduino framework. Libraries

used include: Wire.h (I2C communication for MLX90614 and OLED); Adafruit_GFX.h (graphics

primitives for OLED); Adafruit_SSD1306.h (SSD1306 OLED driver); Adafruit_MLX90614.h

(MLX90614ESF sensor driver).

### 3.9.2 Firmware Logical Architecture

The firmware follows the standard Arduino setup()/loop() architecture.

Setup() initializes all hardware. It configures all motor pins as outputs and sets them LOW,

configures button pins as INPUT_PULLUP, initializes and displays a 5-second startup splash

screen on the OLED, calls mlx.begin() to initialize the temperature sensor and initializes timing

variables.

Loop() implements cooperative multitasking using millis()-based time comparisons for all time-

driven operations:

- Button polling: Each button is polled on every loop iteration. The btnPressed() function checks for LOW state with debounce timing. Mode flags are toggled on confirmed presses, and the display is updated via drawHome().
- Suction motor stepping: If suctionOn is true and the elapsed time since last step exceeds SUCTION_STEP_MS (1 ms), the suction motor advances one half-step.
- Massage motor stepping: If massageOn is true and the elapsed time since last step exceeds MASSAGE_STEP_MS (1 ms), both massage motors advance one step in counter-rotation.
- Temperature reading: If warmingOn is true and the elapsed time since last reading exceeds 4,000 ms, the MLX90614 is read and the display is updated.

### 3.10 Mechanical and Physical Design

### 3.10.1 Swaddle Form Factor

The swaddle form factor was chosen to enable rapid wrapping of the neonate immediately at birth,

positioning the device's sensors and actuators against the baby's body without requiring separate

placement steps. The swaddle consists of a fabric outer layer with integrated channels and pockets

that house the motor assemblies, tubing runs, heating elements, and electronic components. The fabric is designed to conform to the neonate's body under light wrapping tension, maintaining

consistent contact between the compression elements and the chest wall, and consistent proximity

between the temperature sensor and the skin.

3.10.2 3D-Printed Components

Key structural components are 3D-printed from PLA material. 3D-printed components include:

the peristaltic pump head housing and rotor; motor mounting brackets within the swaddle structure;

and the tubing guide channels that route the silicone suction tubing from the pump to the catheter

connection point. PLA was selected for its printability, rigidity, and availability. In a clinical

device, biocompatible materials such as medical-grade silicone or polycarbonate would be

preferred, also keeping in mind their ability to be sterilized.

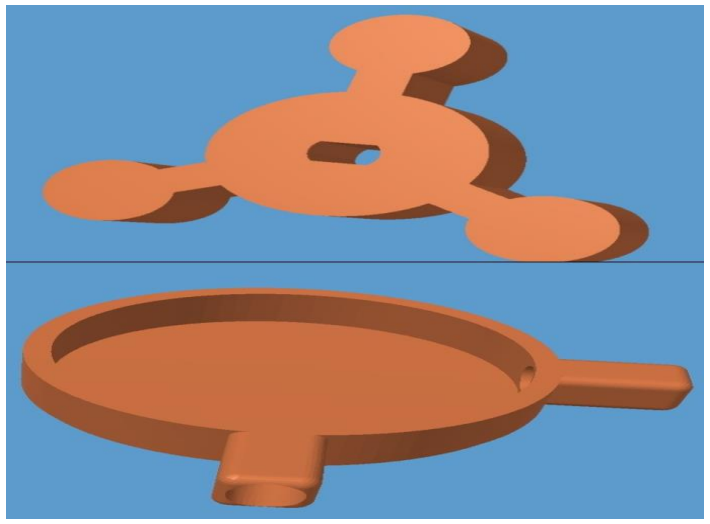
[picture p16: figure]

Figure 13 peristaltic pump 3d designs

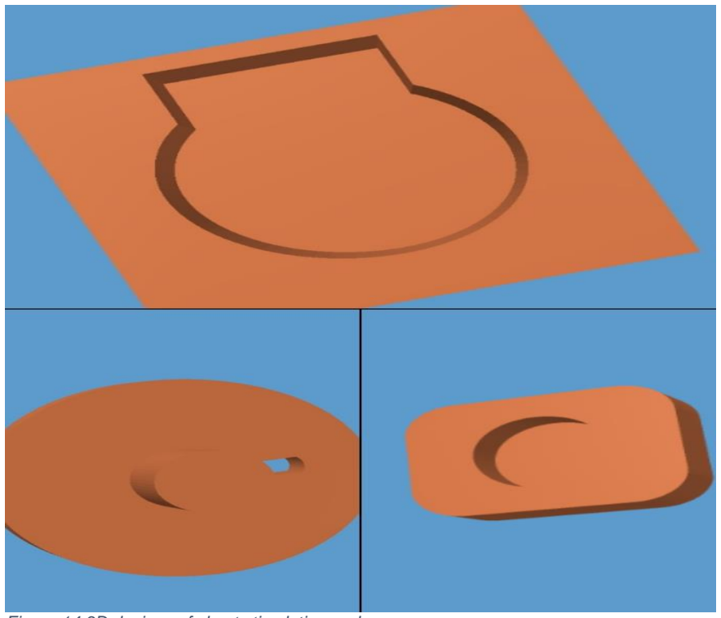
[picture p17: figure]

Figure 14 3D designs of chest stimulation pads

### 3.11 Budget and Bill of Materials

The complete bill of materials for the NERS prototype is presented in the table below. All

components were sourced from PixelElectric, Nairobi, Kenya.

Table 1 Bill of Materials

No. | Component | Quantity | Unit Price (KES) | Total (KES)
1 | GY-906 MLX90614ESF IR Temperature Sensor | 1 | 1,500 | 1,500
2 | 28BYJ-48 Stepper Motor 5VDC Unipolar | 3 | 300 | 900
3 | ULN2003 Stepper Motor Driver Board | 3 | 150 | 450
4 | SSD1306 0.96" I2C OLED Display (White) | 1 | 600 | 600
5 | Red LEDs (5mm) | 10 | 5 | 50
6 | Green LED (5mm) | 1 | 5 | 5
7 | 1/4W 5% Resistor 220kΩ | 11 | 2 | 22
8 | DC Power Supply Module | 1 | 100 | 100
9 | Power Supply Adapter 5V 3A | 1 | 600 | 600

10 | Silicone Pipe | 1 | 60 | 60
11 | Breadboard MB102 | 1 | 250 | 250
12 | Veroboard/Stripboard 6.5cm x 14.5cm | 1 | 100 | 100
13 | Arduino Nano V3.0 | 1 | 1,000 | 1,000
14 | Male-Male Jumper Wire 40pcs Dupont | 1 | 150 | 150
15 | Female-Male Jumper Wire 40pcs Dupont | 1 | 150 | 150
| TOTAL | | | 5,937

### 3.12 Project Timeline

The NERS prototype was developed within a five-day course project timeline as detailed in the

table below.

Table 2 Project Timeline

Day | Activity
Monday | Clinical observation debrief; problem statement refinement; concept note and needs statement development; component selection and budget preparation; procurement of components; initial prototype assembly (motor wiring and driver boards)
Tuesday | Firmware development — stepper motor control, button input, debouncing; OLED display initialization and home screen implementation; temperature sensor library integration and test
Wednesday | Peristaltic pump head 3D printing and assembly; suction tubing routing; compression element mounting in swaddle fabric; integration of all subsystems; firmware integration testing
Thursday | Full prototype testing on neonatal mannequin; all three mode validation; temperature display accuracy check; final assembly and refinement; concept note submission
Friday | Final presentation to assessment panel

## CHAPTER FOUR: RESULTS

### 4.1 Prototype Assembly Overview

A functional prototype of the NERS device was successfully assembled and tested within the five-

day project timeline. The prototype integrates all three operational subsystems, which include

thermal regulation, airway clearance, and chest stimulation. These were all assembled in a single

swaddle form factor, controlled by an Arduino Nano V3.0 microcontroller. The total assembled

cost was KES 5,937.

The electronic assembly was realized on a Veroboard, with the Arduino Nano, three ULN2003

driver boards, and the supporting passive components hand-soldered and connected via Dupont

jumper wires. The power supply adapter whose rating is 5V and 3A, provides power via a DC

barrel connector to the power supply module, which distributes 5V to the Arduino and all

peripherals.

### 4.2 Mode 1 — Thermal Regulation: Performance Results

When button 1 was pressed to activate Mode 1 (Warming), the firmware responded correctly in

all tests. The warmingOn flag was set to true, the heating strip activated, the OLED displayed the

'Baby Warming' confirmation screen for 3 seconds, and the display transitioned to the home screen

with temperature monitoring active.

Temperature readings from the MLX90614ESF sensor were obtained in real time at 4-second

intervals and displayed with one decimal place precision. When the sensor was directed at a surface

at room temperature, approximately 23°C, readings of 22.8–23.2°C were recorded, consistent with

sensor specifications. When directed at a warm surface, approximately 36.5°C, readings of 36.3–

36.7°C were obtained. The OLED correctly displayed 'OK', '! LOW', or '! HIGH' adjacent to the

temperature value based on the defined thresholds (<36.0°C, 36.0°C–37.5°C, >37.5°C

respectively), in all test conditions.

The button debounce logic prevented false triggering in all tests. Toggling the mode off deactivated

the heating strip and returned the display to the non-warming home screen layout. No I2C

communication errors were encountered during temperature reading tests.

### 4.3 Mode 2 — Airway Clearance: Performance Results

When button 2 was pressed to activate Mode 2 (Suction), the suctionOn flag was set to true, and

the suction motor began stepping through the half-step sequence at 1 ms per step. The OLED

updated to show '[SUCTION ON]' in the suction mode line.

Mechanical testing of the peristaltic pump confirmed that the motor successfully drove the pump

rotor, producing visible compression and release of the silicone tubing in a peristaltic wave pattern.

When button 2 was pressed again to deactivate suction, motor rotation was stopped immediately.

### 4.4 Mode 3 — Chest Stimulation: Performance Results

When button 3 was pressed to activate Mode 3 (Massage), the massageOn flag was set to true, and

both massage motors began stepping simultaneously. The left motor rotated in reverse direction,

and the right motor in forward direction. The OLED updated to show '[MASSAGE ON]' in the

massage mode line.

Physical testing confirmed that the counter-rotation of the two motors produced a coordinated

bilateral compressive motion at the compression elements. When the device was placed on a

neonatal mannequin, the compression elements made contact with the chest wall and delivered

rhythmic compression and release cycles.

The step rate of 1 ms per step produced a smooth, continuous motion rather than the discrete

stepping noticeable at lower frequencies. When button 3 was pressed to deactivate massage,

stopMotor() was correctly called for both the left motor and the right motor, halting both motors

simultaneously.

### 4.5 User Interface and Display Validation

The OLED display functioned correctly in all tested scenarios. The startup splash screen ('THE

NERS' in size-2 text, 'Neonatal Response' and 'Swaddle v1.0' in size-1 text) displayed correctly

for 5 seconds on power-on. The home screen correctly reflected the state of all three mode flags

in real time. Button options display at the bottom of the screen provided persistent operational

guidance to the user.

The combined I2C bus operation of the MLX90614ESF (address 0x5A) and SSD1306 OLED

(address 0x3C) was verified to function without conflict. Both devices responded correctly to I2C communication throughout all tests. No address conflicts or communication failures were

encountered.

### 4.6 Integrated System Testing

The NERS prototype was tested with all three modes activated simultaneously to verify that

concurrent operation of all three subsystems did not cause interference or system failure.

Simultaneous activation of warming mode, suction motor, and massage motors was confirmed to

operate correctly, with all three modes functioning independently and the OLED correctly

displaying all three active mode indicators alongside the temperature reading.

The table below summarizes the performance outcomes of the prototype testing across all modes.

Table 3 Performance outcomes

Subsystem | Test Performed | Result | Pass/Fail
Thermal Regulation | Temperature display at room temperature | 22.8–23.2°C displayed, '! LOW' shown | Pass
Thermal Regulation | Temperature display at body temperature range

36.3–36.7°C
displayed, 'OK'
shown

Pass

Thermal Regulation | Alert at simulated fever temperature | '! HIGH' displayed above 37.5°C | Pass
Thermal Regulation | LED activation on mode enable | RED_LED activated on BTN1 press | Pass
Airway Clearance | Motor rotation on BTN2 press

Suction motor
stepped correctly

Pass

Airway Clearance Fluid flow through tubing

Visible flow
generated by
peristaltic action

Pass

Airway Clearance Motor stop on BTN2 press

All motor coils de-energized

Pass

Chest Stimulation Counter-rotation of dual motors

Both motors step in
opposing directions

Pass

Chest Stimulation Compression element motion on mannequin

Rhythmic
compression
observed on chest
wall

Pass

Chest Stimulation Motor stop on BTN3 press

Both motors halted
simultaneously

Pass

User Interface | OLED startup display | Correct startup screen 5 seconds | Pass
User Interface | I2C bus shared operation | No conflicts — both devices responsive | Pass
Integration | Concurrent three- mode operation

All modes functional
simultaneously

Pass

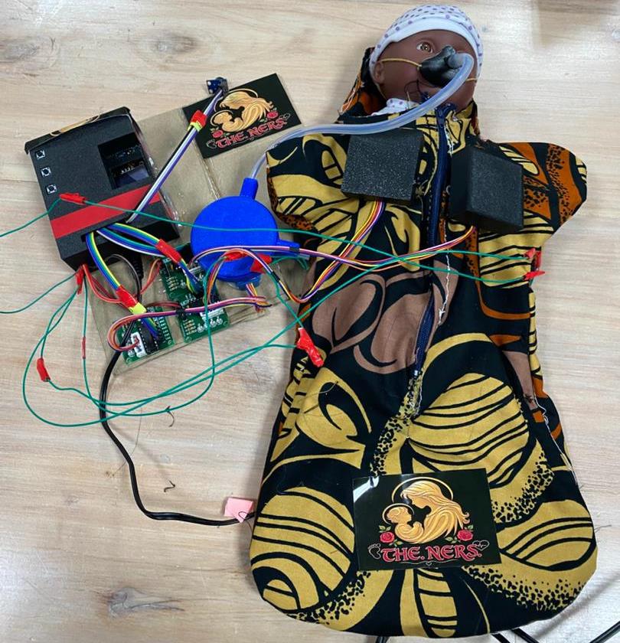
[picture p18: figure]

Figure 15 Device Prototype

## CHAPTER FIVE: DISCUSSION

### 5.1 Clinical Significance

The NERS device addresses a specific and well-documented clinical point of failure in neonatal

emergency care in low-resource Kenyan health facilities. This is the fragmentation of the three

primary resuscitation interventions across separate, non-integrated devices that must be managed

sequentially by a single birth attendant under acute time pressure within the Golden Minute.

The clinical significance of this problem is quantified in the literature. The 16% increase in

mortality risk for every 30-second delay in ventilation, documented by Mwangi et al. (2018),

shows the gravity of the situation, and why it must be addressed [6]. If a birth attendant requires

30 seconds to connect the suction machine before initiating airway clearance, and another 30

seconds to transition from suction to chest compressions, that 60-second combined delay

represents approximately a 32% elevation in mortality risk. This can be solved easily an integrated

device. This is not a marginal improvement. It is potentially the difference between survival and

death.

The thermal regulation component addresses a separate but concurrent risk. Wainaina et al. (2024)

documented that 17.5% of neonates admitted to Kenyan hospitals arrive hypothermic, with

hypothermia associated with a 35% increase in odds of death [8]. In a non-breathing neonate

requiring resuscitation, hypothermia risk is even higher, as the infant is not crying, which generates

body heat through muscular effort. NERS addresses this risk automatically, by wrapping the

neonate in the device. Thermal regulation begins at the same moment as other resuscitation

interventions, without any additional step by the attendant.

The airway clearance function directly replicates the manual suction step observed at Thika Level

5 Hospital and documented in neonatal resuscitation guidelines as a necessary early intervention

for non-vigorous newborns with airway obstruction [18]. By integrating this function into the

swaddle, NERS eliminates the need for the attendant to reach for and connect a separate suction

catheter and machine, which is a step that requires both hands and physical movement away from

the infant.

The chest stimulation function addresses the operator-dependency problem in manual chest

compression. ILCOR guidelines specify a compression rate of 90 per minute and a depth of one-third of the anterior-posterior diameter of the neonatal chest [19]. Achieving and maintaining these

parameters manually under acute stress, while simultaneously managing an airway, is difficult.

The BabySaver feasibility study in Uganda (2025) demonstrated that an integrated resuscitation

support reduced time to successful resuscitation from a median of 8 minutes to 5 minutes [24].

NERS builds on this evidence base with a lower-cost, more comprehensive integration.

### 5.2 Technical Performance Analysis

The prototype demonstrated correct operation of all three modes in all test conditions. The use of

the 28BYJ-48 stepper motor at 1 ms per step produced smooth, continuous motion for both the

suction pump and the compression elements, avoiding the mechanical resonance and vibration that

occurs at step rates close to the motor's natural frequency. The half-step drive sequence provides

smoother rotation and more torque at low speeds, both of which are important for the precision

and gentleness required in a neonatal device.

The MLX90614ESF sensor performed accurately within the body temperature range in prototype

testing, consistent with its published accuracy specification of ±0.5°C [27]. The I2C bus sharing

between the temperature sensor (address 0x5A) and the OLED display (address 0x3C) was

implemented without address conflict, confirming the feasibility of this bus topology for resource-

constrained single-microcontroller implementations.

The firmware's cooperative multitasking implementation, using millis()-based timing rather than

hardware interrupts, performed adequately for the task demands of this prototype. All three modes'

timing-critical operations (stepper motor stepping at 1 ms intervals, temperature reading at 4 s

intervals) were maintained without observable timing degradation during concurrent operation.

The power consumption of approximately 820 mA at 5V during full concurrent operation is within

the capacity of the 5V 3A power supply used in the prototype.

### 5.3 Cost-Effectiveness and Deplorability

At a total cost of KES 5,937, NERS achieves cost-effectiveness that is without precedent among

integrated neonatal resuscitation devices. The BabySaver platform, the most comparable

commercially available device in terms of integrated resuscitation support philosophy, costs

significantly more and requires importation from Norway. This introduces supply chain barriers that limit availability in resource-constrained settings. Standard wall-mounted suction units in

Kenyan public hospitals cost approximately KES 15,000–25,000 and provide only the suction

function, without thermal regulation, chest stimulation, or integrated control.

The components used in NERS are available from a single Kenyan supplier (PixelElectric,

Nairobi), eliminating import logistics. The Arduino Nano, 28BYJ-48 motors, and SSD1306 OLED

display are globally standardized components available in virtually every country in the world,

ensuring supply chain resilience and replaceability. The 3D-printed structural components can be

fabricated using consumer-grade printers, which are now present at multiple Kenyan universities

and makerspaces.

Kenya's Newborn and Child Health Strategic Plan 2022–2026 explicitly targets affordable,

scalable innovations for facility-level neonatal care improvement [12]. NERS aligns with this

policy framework at a price point that makes procurement feasible for Level 4 and 5 facilities

within their existing equipment budgets.

### 5.4 Comparison with Existing Technologies

The table below presents a comparative analysis of NERS against current approaches to neonatal

resuscitation support in Kenyan low-resource settings.

Table 4 Comparison with existing technologies

Parameter | Current Standard (Fragmented) | BabySaver + NeoBeat | NERS Prototype
Thermal regulation | Separate radiant warmer | Not integrated | Integrated (heating + IR sensor)
Airway clearance | Separate suction machine | Not integrated | Integrated (peristaltic pump)
Chest stimulation | Manual (two fingers) | Not automated | Integrated (dual stepper motors)
Single-device deployment | No | Partial | Yes
Time to deploy | Multiple steps | Faster than standard | Single wrap application
Single-operator capable | With difficulty | Yes | Yes

Cost (approx. USD) >USD 1,000
combined
Higher cost, imported | USD 46
Locally sourced | Partially | No (imported) | Yes (PixelElectric, Nairobi)
Vital signs monitoring | Separate oximeter (if available) | NeoBeat HR monitor | Temperature only (v1.0)

Battery/off-grid
capable
No (grid-dependent) | Limited | Yes (5V battery bank)

The comparative analysis demonstrates that NERS offers a unique combination of three-function

integration, single-device deployment capability, and low cost that is not available in any current

commercial or research device. Its primary current limitation, the absence of heart rate and oxygen

saturation monitoring, is directly addressed in the planned future development phase.

### 5.5 Limitations and Areas for Improvement

### 5.5.1 Force and Pressure Calibration

The most significant technical limitation of the current prototype is the absence of instrumented

force and pressure calibration. ILCOR guidelines specify chest compression depth as

approximately one-third of the anterior-posterior diameter of the neonatal chest [19 The current

prototype has not been instrumented to measure actual compression force or depth. Future work

must include force plate testing of the compression elements to verify that the motor torque and

cam geometry produce compression depths within the target range, and must include compliance

testing across a range of neonatal chest stiffnesses which varies with gestational age and birth

weight.

Similarly, the suction pressure generated by the peristaltic pump has not been measured. Clinical

guidelines specify suction pressure ranges for neonatal airway clearance. Compliance with these

limits requires pressure sensor validation. Excessive suction pressure can cause mucosal injury in

the neonatal airway, making this calibration clinically critical prior to any human use.

### 5.5.2 Biocompatibility and Sterilization

The materials used in the current prototype, PLA 3D prints, silicone tubing, and clothes, are not

certified as biocompatible for direct neonatal skin contact. A clinical device would require:

biocompatibility testing per ISO 10993-1 (Biological evaluation of medical devices); replacement of PLA with medical-grade materials (e.g., polycarbonate, ABS, or silicone) and validation of

sterilization protocols compatible with all components.

### 5.5.3 Vital Signs Monitoring Integration

The current prototype monitors only temperature. The absence of continuous heart rate monitoring

is a clinically significant gap. ILCOR guidelines use heart rate as the primary determinant of when

to initiate chest compressions (<60 bpm), when to continue ventilation (<100 bpm), and when

resuscitation has succeeded (>100 bpm) [18, 19]. Integration of a pulse oximetry module, such as

the MAX30102, which provides both heart rate and SpO2 on a single chip, would transform NERS

from a resuscitation actuator device into a closed-loop device that can modify its interventions

based on the neonate's physiological response.

### 5.5.4 Form Factor and Portability

The current prototype's electronics are housed externally on Veroboard within a 3D-printed

enclosure attached to the swaddle. This configuration, while functional for prototype validation,

creates a device that is bulkier and more fragile than a production design. A custom PCB

integrating the Arduino Nano, ULN2003 drivers, power regulation, and all passive components

would reduce the electronics footprint to approximately the size of a credit card, enabling full

integration within the swaddle structure.

### 5.5.5 Clinical Validation Pathway

Moving from a successfully tested prototype to a clinically deployable device requires a defined

validation pathway, which include:

1. biomechanical testing on physical neonatal chest simulators to calibrate compression depth

and force.

2. suction pressure measurement and validation against clinical standards.
3. animal or phantom model testing of integrated function.
4. ethical review and clinical trial protocol development.
5. regulatory approval by the Kenya Pharmacy and Poisons Board (KPPB) under the Medical

Devices and In Vitro Diagnostic Devices Regulations 2012.

## CHAPTER SIX: CONCLUSION AND RECOMMENDATIONS

### 6.1 Conclusion

This project successfully designed, developed, programmed, assembled, and prototype-tested the

Neonatal Emergency Response Swaddle (NERS): a single integrated device providing automated

thermal regulation, airway clearance, and rhythmic chest stimulation for non-breathing newborns

at the point of delivery in low-resource health facilities.

The device directly addresses a documented clinical problem: the fragmentation of neonatal

resuscitation interventions across multiple separate devices in Kenyan public health facilities,

which introduces procedural delays within the Golden Minute that the literature associates with a

16% increase in mortality risk per 30-second delay. Birth asphyxia, the leading cause of neonatal

mortality in Kenya at 31.6% of all newborn deaths, claims many Kenyan newborn lives annually

and leaves many more with permanent neurological injury. NERS is designed to reduce the

procedural contribution to this burden.

The prototype integrates three 28BYJ-48 stepper motors for suction and compression actuation,

an MLX90614ESF infrared temperature sensor for non-contact thermal monitoring, a SSD1306

OLED display for real-time status and temperature readout, and an Arduino Nano V3.0 as the

central controller, all within a swaddle form factor at a total bill of materials cost of KES 5,937.

All three operational modes were validated through mannequin testing, confirming correct

mechanical, electronic, and firmware function.

The NERS project establishes a proof of concept that integrated, multi-function neonatal

resuscitation support can be achieved at a cost accessible to Level 4 and 5 Kenyan public health

facilities, using locally sourced components and open-source firmware. The fundamental

engineering goal of integrating three separate resuscitation functions into one deployable device,

has been demonstrated.

It is important to state clearly what the current prototype is and is not. It is a validated proof of

concept demonstrating functional integration of three resuscitation modalities at target cost and in

the target form factor. It is not yet a clinical device, as it has not undergone force calibration,

pressure validation, biocompatibility testing, or any form of clinical trial involving human patients.

These steps define the future work required to translate this proof of concept into a deployable

clinical innovation.

### 6.2 Recommendations

### 6.2.1 Immediate Technical Enhancements

- Instrumented force calibration: Use a load cell or pressure-sensitive film to measure the compression force delivered by the massage motors across a range of cam geometries, and calibrate to achieve compression depth of one-third of the anterior-posterior neonatal chest diameter.
- Suction pressure measurement: Instrument the suction system with a miniature pressure transducer to measure generated negative pressure and calibrate the motor step rate to achieve clinically safe suction levels, consistent with neonatal airway suction guidelines.
- Custom PCB development: Design a custom PCB integrating all components. This will reduce electronics footprint, improve reliability, and enable full swaddle integration.
- Vital signs integration: Integrate a pulse oximetry module via the existing I2C bus to provide continuous heart rate and SpO2 monitoring, enabling real-time assessment of resuscitation response.
- Battery power subsystem: Develop an integrated rechargeable battery subsystem, enabling off-grid deployment without dependence on AC power.

### 6.2.2 Biomechanical Development

- Chest pad optimization: Partner with a biomedical engineer specializing in neonatal anatomy to optimize the compression pad geometry, contact area, and material compliance for the range of birth weights encountered in Kenyan hospitals.
- Testing on physical neonatal chest simulators: Use validated neonatal manikins with instrumented chest modules to systematically characterize compression force-depth relationships across the full motor speed and cam geometry.

### 6.2.3 Clinical Validation Pathway

- Ethical approval: Submit a research protocol to the Kenyatta National Hospital/University of Nairobi Ethics and Research Committee (KNH-UoN ERC) for the first phase of simulated delivery room validation with healthcare provider participants (no patient exposure at this stage).

- Healthcare provider usability study: Conduct structured usability testing with birth attendants at Thika Level 5 Hospital and at least one rural Level 4 facility, assessing time-to-deployment, mode activation accuracy under simulated emergency conditions, and user confidence assessment.
- Regulatory pathway engagement: Engage the Kenya Pharmacy and Poisons Board (KPPB) Medical Devices Regulatory Division at an early stage to understand the registration requirements and establish a regulatory submission timeline aligned with the clinical validation programme.

### 6.2.4 Research and Publication

- Publish a peer-reviewed design paper documenting the NERS concept, engineering design decisions, prototype testing results, and cost analysis, targeting journals such as IEEE Journal of Translational Engineering in Health and Medicine, or BMC Medical Devices.
- Explore collaboration with the KEMRI-Wellcome Trust Research Programme (Nairobi) or Aga Khan University Kenya for the clinical validation phase, leveraging their existing neonatal research infrastructure and ethical oversight capacity.

### 6.2.5 Funding and Scale-Up

- Apply for seed funding through Kenyan innovation ecosystems including the Kenya Medical Research Institute (KEMRI) Innovation Fund, the Kenya Climate Innovation Centre (KCIC), and international channels such as the Grand Challenges Canada Stars in Global Health Programme, which has funded multiple low-cost medical device innovations originating from East African universities.
- Engage the Kenya Ministry of Health's Kenya Medical Supplies Authority (KEMSA) at an appropriate stage of development to explore procurement pathway discussions for national-scale deployment.

## REFERENCES

[1] UNICEF. Kenya Maternal and Newborn Health Disparities. UNICEF, New York, USA.
[Online]. | Available: | https://data.unicef.org/wp-content/uploads/cp/maternal-newborn-

health/maternal-and-newborn-health_KEN.pdf

[2] UN Inter-Agency Group for Child Mortality Estimation. "Levels and Trends in Child Mortality

Report 2025." UNICEF, WHO, World Bank, UN DESA, 2025.

[3] UNICEF, African Union & UNECA. State of African Children Statistical Compendium 2025.

Nairobi: UNICEF, 2025.

[4] Kenya National Bureau of Statistics. "Kenya Demographic and Health Survey 2022." KNBS,

Nairobi, Kenya, 2023.

[5] J. Aluvaala et al., "Neonatal mortality in Kenyan hospitals: a multisite, retrospective, cohort

study," BMJ Global Health, vol. 6, no. 5, p. e004475, 2021. doi: 10.1136/bmjgh-2020-004475

[6] B. Mwangi et al., "Practice and outcomes of neonatal resuscitation for newborns with birth

asphyxia at Kakamega County General Hospital, Kenya," BMC Pediatrics, vol. 18, no. 1, p. 166,

2018. doi: 10.1186/s12887-018-1127-6

[7] J. B. Asiimwe et al., "Quality of newborn care and associated factors: An analysis of the 2022

Kenya demographic and health survey," PLOS Global Public Health, vol. 4, no. 11, p. e0003677,

2024. doi: 10.1371/journal.pgph.0003677

[8] J. Wainaina et al., "Hypothermia amongst neonatal admissions in Kenya: a retrospective cohort

study assessing prevalence, trends, associated factors, and its relationship with all-cause neonatal

mortality," Frontiers in Pediatrics, vol. 12, p. 1272104, 2024. doi: 10.3389/fped.2024.1272104

[9] B. Olack et al., "Causes of preterm and low birth weight neonatal mortality in a rural

community in Kenya: evidence from verbal and social autopsy," BMC Pregnancy and Childbirth,

vol. 21, no. 1, p. 531, 2021. doi: 10.1186/s12884-021-04012-z

[10] Thingiverse Community. "Peristaltic pump for single 28BYJ-48 stepper motor." [Online].

Available: https://www.thingiverse.com/thing:664381. Accessed: 2025.

[11] OEM Secrets. "Embedded System for Contactless Temperature Measurement in Healthcare

Management." [Online]. Available: https://www.oemsecrets.com/articles/embedded-system-for-

contactless-temperature-measurement-in-healthcare-management. 2024.

[12] Ministry of Health, Republic of Kenya. "Newborn and Child Health Strategic Plan 2022–
2026." | Nairobi: | MOH | Kenya, | 2022. | [Online]. | Available:

http://guidelines.health.go.ke:8000/media/Newborn_and_Child_Health_Stategic_plan_2022_-

_2026.pdf

[13] United Nations. "Sustainable Development Goal 3: Ensure healthy lives and promote well-

being for all at all ages." UN SDG Monitor, 2015.

[14] S. Ramachandran et al., "Neonatal Cardiac Compressions Scoping Review and Task Force

Insights." ILCOR NLS Task Force, 2022. [Online]. Available: https://costr.ilcor.org

[15] S. Schnaubelt et al., "Cardiopulmonary resuscitation in low-resource settings: a statement by

the International Liaison Committee on Resuscitation," The Lancet Global Health, vol. 11, no. 9,

pp. e1360–e1368, 2023. doi: 10.1016/S2214-109X(23)00302-9

[16] B. B. Masaba and R. M. Mmusi-Phetoe, "Neonatal Survival in Sub-Sahara: A Review of

Kenya and South Africa," Journal of Multidisciplinary Healthcare, vol. 13, pp. 709–718, 2020.

doi: 10.2147/JMDH.S249812

[17] Kisumu County Government. "Kenya Races Against Time to Reduce Newborn Deaths."
Kisumu | County | Government | Health | Report, | June | 2024. | [Online]. | Available:

https://www.kisumu.go.ke/kenya-races-against-time-to-reduce-newborn-deaths/

[18] American Heart Association & American Academy of Pediatrics. "2023 Focused Update on

Neonatal Resuscitation: An Update to the AHA Guidelines for CPR and ECC," Circulation, vol.

149, no. 5, 2024. doi: 10.1161/CIR.0000000000001181

[19] International Liaison Committee on Resuscitation. "Neonatal Life Support: 2025 ILCOR

Consensus on Science With Treatment Recommendations," Circulation, vol. 152, Suppl 1, 2025.

doi: 10.1161/CIR.0000000000001363

[20] World Health Organization. "Thermal Protection of the Newborn: A Practical Guide."

WHO/RHT/MSM/97.2. Geneva: WHO, 1997. [Referenced in current clinical practice guidelines]

[21] M. Kyokan et al., "Neonatal warming devices: What can be recommended for low-resource

settings when skin-to-skin care is not feasible?" Frontiers in Pediatrics, vol. 11, p. 1171258, 2023.

doi: 10.3389/fped.2023.1171258

[22] ILCOR NLS Task Force. "2023 ILCOR Scoping Review — Comparison of techniques for

providing cardiac compressions in neonates." ILCOR Continuous Evidence Evaluation, 2023.

[Online]. Available: https://costr.ilcor.org

[23] M. Bruckner et al., "Chest Compression Rates of 90/min versus 180/min during Neonatal

Cardiopulmonary Resuscitation: A Randomized Controlled Animal Trial," Children, vol. 9, no.

12, p. 1838, 2022. doi: 10.3390/children9121838

[24] M. W. Musaba et al., "Feasibility and acceptability of using the BabySaver resuscitation

platform and NeoBeat together for neonatal resuscitation in a low-resource setting: A pre-post

implementation study," PLOS ONE, 2025. doi: 10.1371/journal.pone.0337088

[25] ScienceDirect. "From constraints to solutions: leveraging low-cost, scalable simulation for

safer neonatal resuscitation." ScienceDirect article, April 2026.

[26] NeoWarm Research Group. "Development of AI-integrated infrastructure with biomedical

device and mobile app for neonatal vital monitoring during and in between kangaroo care

sessions." arXiv preprint, arXiv:2509.10489, 2025.

[27] Melexis. "MLX90614 Family — Single and Dual Zone Infrared Thermometer in TO-39 and

SOIC8." Datasheet, Rev. 10. Melexis NV, 2019.

[28] A. L. Solevag et al., "Delivery Room Handling of the Newborn: Filling the Gaps,"

Neonatology, vol. 121, no. 5, pp. 553–561, 2024. doi: 10.1159/000540079

[29] M. Bruckner et al., "Chest compression rates of 60/min versus 90/min during neonatal

cardiopulmonary resuscitation: a randomized controlled animal trial," Frontiers in Pediatrics, vol.

11, p. 1214513, 2023. doi: 10.3389/fped.2023.1214513

[30] Microcontrollers Lab. "MLX90614 Contactless IR Temperature Sensor Interfacing with
Arduino." | [Online]. | Available: | https://microcontrollerslab.com/mlx90614-contactless-ir-

temperature-sensor-pinout-interfacing-arduino/. 2025.

[31] Down to Earth. "Neonatal mortality rate in Kenya shows no significant change in 8 years:

Survey." April 2024. [Online]. Available: https://www.downtoearth.org.in/africa/neonatal-

mortality-rate-in-kenya-shows-no-significant-change-in-8-years-survey-87230

[32] Nation Africa. "Kenya slashes under-five deaths by 62pc, but newborn survival stalls." March

28, 2026. [Online]. Available: https://nation.africa/kenya/health/kenya-slashes-under-five-deaths-

by-62pc-but-newborn-survival-stalls-5402396

[33] Adafruit Industries. "Adafruit MLX90614 Library for Arduino." GitHub Repository.

[Online]. Available: https://github.com/adafruit/Adafruit-MLX90614-Library

[34] Adafruit Industries. "Adafruit SSD1306 Library for Arduino." GitHub Repository. [Online].

Available: https://github.com/adafruit/Adafruit_SSD1306

## APPENDICES

APPENDIX A: COMPONENT DATASHEETS AND SPECIFICATIONS SUMMARY

Table 5 Component Specifications

Component | Manufacturer | Key Specifications | Datasheet Reference
Arduino Nano V3.0 | Arduino / Various | ATmega328P, 16 MHz, 14 DIO, 8 AIO, 5V, 32KB Flash | Arduino Nano Datasheet Rev C3

28BYJ-48 Stepper
Motor

Various
(CNC)

5VDC, 4-phase unipolar,
64:1 gear, 2048 steps/rev, 240mA/phase

28BYJ-48 Technical
Datasheet

ULN2003 Driver
Board
| Various | 500mA/ch, 7-channel Darlington array, flyback diodes

TI ULN2003A
Datasheet
MLX90614ESF | Melexis | IR thermopile, ±0.5°C accuracy, 17-bit ADC, I2C, - 70 to +382°C

Melexis MLX90614
Datasheet Rev.10
SSD1306 OLED | Solomon Systech | 128x64px, I2C address 0x3C, 3.3/5V, 20mA max

SSD1306 Datasheet
Rev 1.1
Power Adapter 5V 3A | Various | 5VDC output, 3A max, DC barrel connector

Product specification
sheet

APPENDIX B: PIN MAPPING TABLE — ARDUINO NANO V3.0

Table 6 PIn mapping table

Pin | Connected To | Function | Mode
D2 | ULN2003 #3 — IN1 | Suction motor coil 1 | OUTPUT
D3 | ULN2003 #3 — IN2 | Suction motor coil 2 | OUTPUT
D4 | ULN2003 #2 — IN1 | Right motor coil 1 | OUTPUT
D5 | ULN2003 #2 — IN2 | Right motor coil 2 | OUTPUT
D6 | ULN2003 #2 — IN3 | Right motor coil 3 | OUTPUT
D7 | ULN2003 #2 — IN4 | Right motor coil 4 | OUTPUT
D8 | ULN2003 #1 — IN1 | Left motor coil 1 | OUTPUT
D9 | ULN2003 #1 — IN2 | Left motor coil 2 | OUTPUT
D10 | ULN2003 #1 — IN3 | Left motor coil 3 | OUTPUT

D11 | ULN2003 #1 — IN4 | Left motor coil 4 | OUTPUT
D12 | ULN2003 #3 — IN3 | Suction motor coil 3 | OUTPUT
D13 | ULN2003 #3 — IN4 | Suction motor coil 4 | OUTPUT
A0 | Push Button BTN1 | Warming mode toggle | INPUT_PULLUP
A1 | Push Button BTN2 | Suction mode toggle | INPUT_PULLUP
A2 | Push Button BTN3 | Massage mode toggle | INPUT_PULLUP
A3 | Red LED (via 220Ω) | Warming active indicator | OUTPUT
A4 (SDA) | MLX90614 SDA + OLED SDA | I2C data line (shared) | I2C
A5 (SCL) | MLX90614 SCL + OLED SCL | I2C clock line (shared) | I2C
5V | All VCC rails | Power supply | Power
GND | All GND rails | Common ground | Power

APPENDIX C: GLOSSARY OF CLINICAL TERMS

APGAR Score: A standardized neonatal assessment tool evaluating five parameters at 1 and 5

minutes after birth: Appearance (skin color), Pulse (heart rate), Grimace (reflex irritability),

Activity (muscle tone), and Respiration. Scores range from 0 to 10; scores below 7 at 5 minutes

indicate the need for resuscitation assessment.

Birth Asphyxia: Failure to initiate and sustain spontaneous breathing at birth, resulting in

progressive hypoxia, hypercapnia, and metabolic acidosis.

Golden Minute: The first 60 seconds following birth, during which initiation of resuscitation is

most effective in preventing mortality and neurological injury.

Hypoxic-Ischaemic Encephalopathy (HIE): Brain injury resulting from insufficient oxygen and

blood flow to the brain during the perinatal period. Classified as mild, moderate, or severe; severe

HIE carries a high risk of death or permanent disability.

Neonatal Mortality Rate (NMR): Number of deaths occurring in the first 28 days of life per 1,000

live births in a given year. The global average is approximately 18 per 1,000. Kenya's rate is 20.7

per 1,000 (2024).

Peristaltic Pump: A positive-displacement pump that moves fluid by sequentially compressing a

flexible tube. Named for peristalsis, the wave-like muscular contractions of the digestive tract.

Resuscitaire: A heated, open-topped cot with radiant warmer and flat work surface used as the

standard point of delivery for neonatal resuscitation in hospital settings.

Suction Catheter: A flexible tube connected to a suction source, inserted into the neonatal airway

to remove secretions, fluid, or meconium.

Term Neonate: A newborn of 37–42 completed weeks of gestational age. The NERS prototype is

designed for term neonates; adaptation for preterm neonates would require separate size and force

calibration.

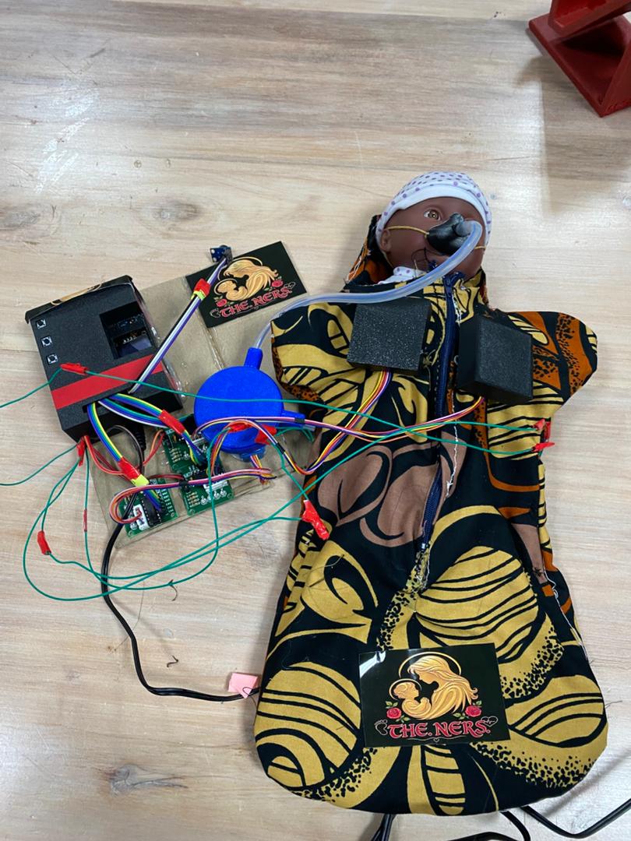
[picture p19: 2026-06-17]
IMAGES/PROTOTYPE.jpeg

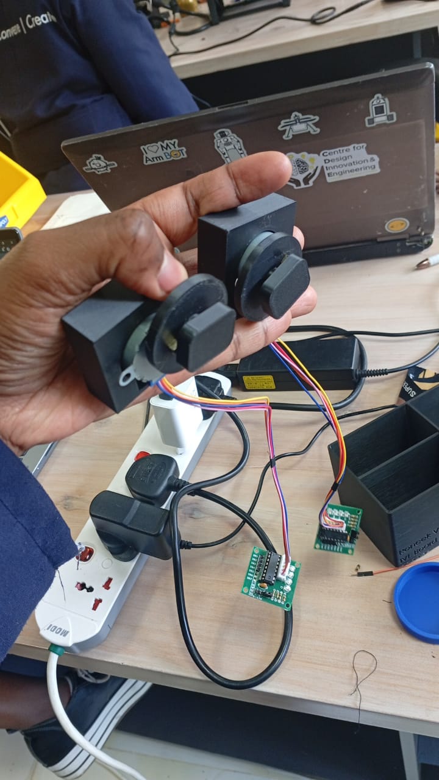
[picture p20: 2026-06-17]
IMAGES/CHEST COMPRESSION PADS.jpeg

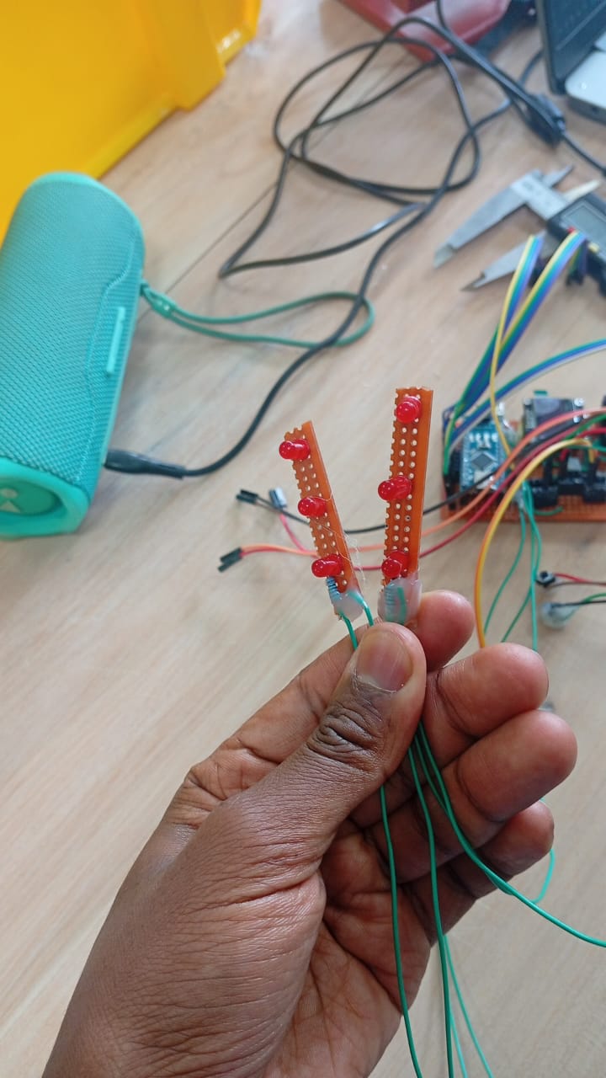
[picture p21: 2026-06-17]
IMAGES/LED HEATING STRIPS.jpeg

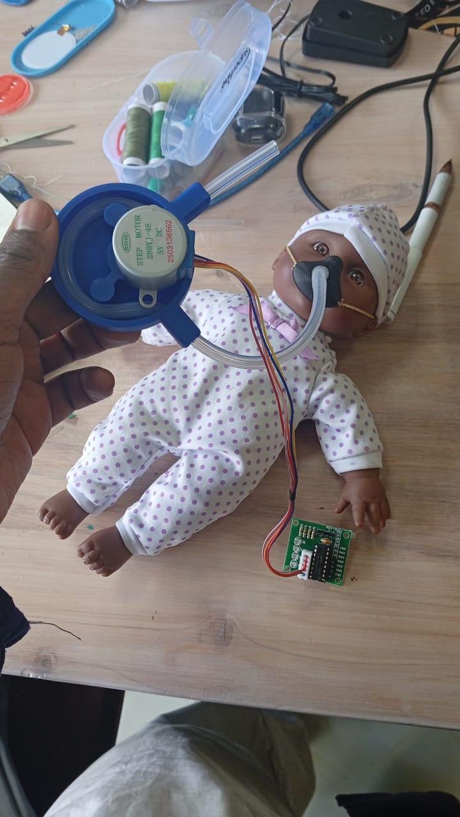
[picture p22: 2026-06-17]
IMAGES/SUCTION.jpeg

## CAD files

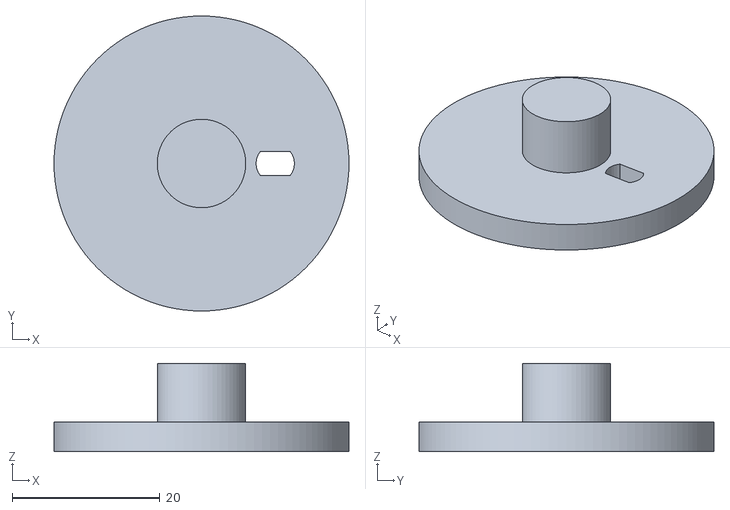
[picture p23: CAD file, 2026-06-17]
3D DESIGNED PARTS/cam disk.stl
40.0 x 40.0 x 12.0

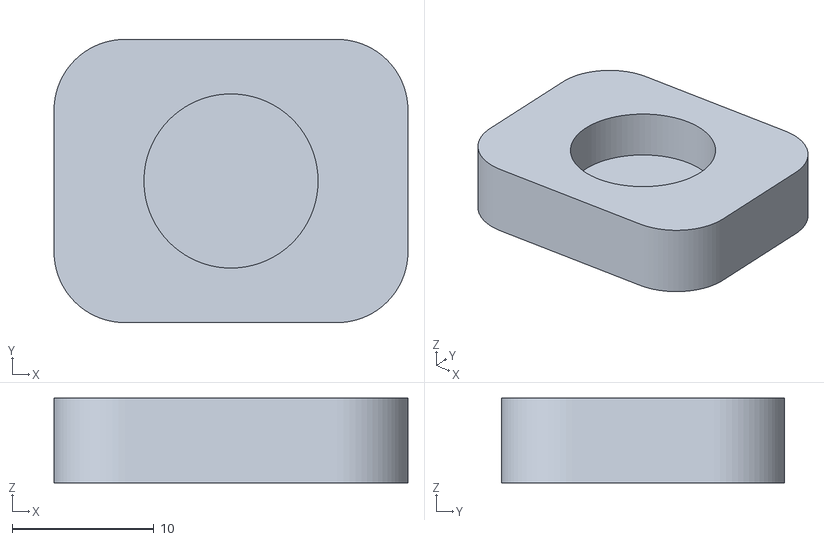
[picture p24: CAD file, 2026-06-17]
3D DESIGNED PARTS/pad.stl
25.0 x 20.0 x 6.00

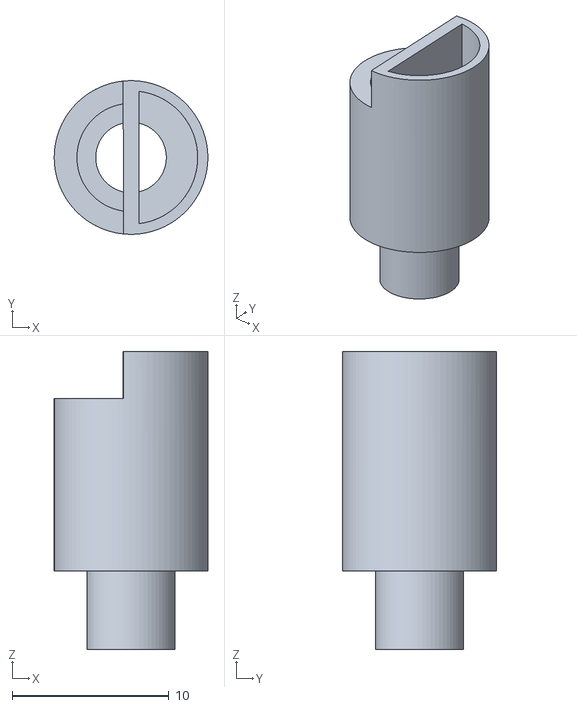
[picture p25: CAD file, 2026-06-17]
3D DESIGNED PARTS/tube.stl
9.80 x 9.80 x 19.0

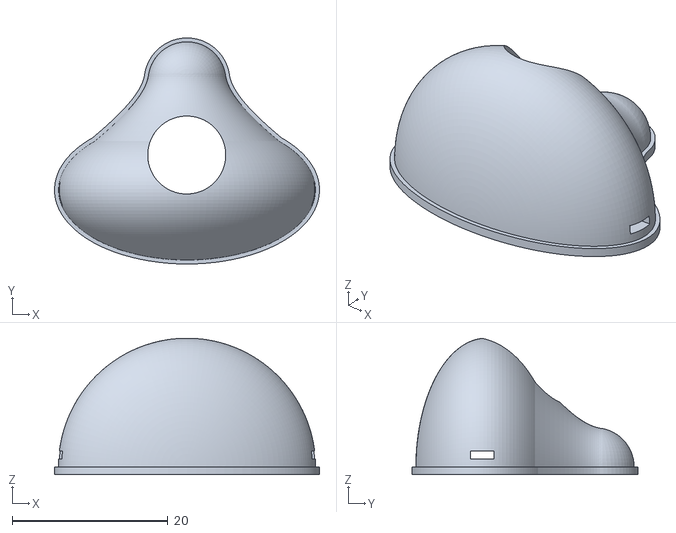
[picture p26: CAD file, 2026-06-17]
3D DESIGNED PARTS/mouth.stl
34.0 x 29.0 x 17.5

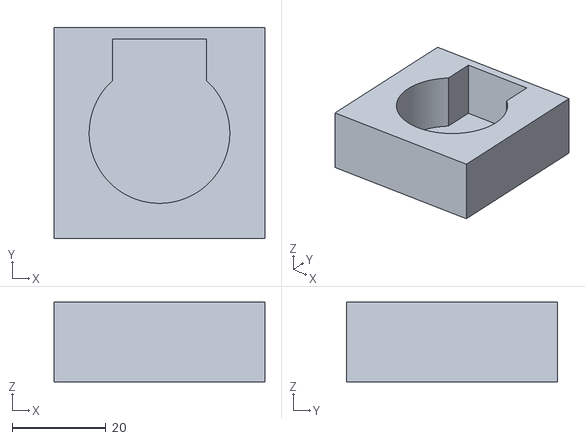
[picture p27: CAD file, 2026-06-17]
3D DESIGNED PARTS/mount.stl
45.0 x 45.0 x 17.0

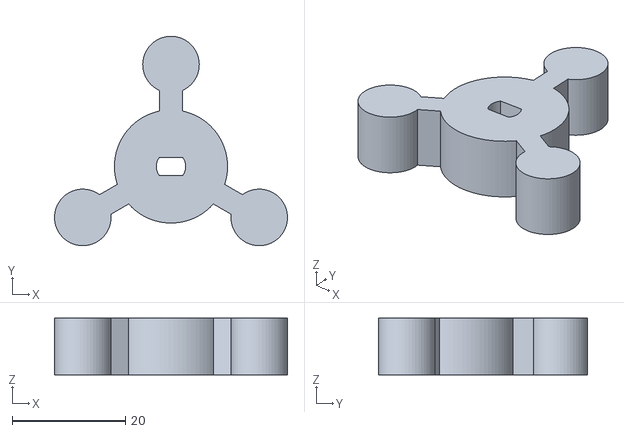
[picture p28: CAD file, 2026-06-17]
3D DESIGNED PARTS/pump part.stl
41.2 x 37.0 x 10.0

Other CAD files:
3D DESIGNED PARTS/pumppart.stl

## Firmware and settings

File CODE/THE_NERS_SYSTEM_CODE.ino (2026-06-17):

#include <Wire.h>
#include <Adafruit_GFX.h>
#include <Adafruit_SSD1306.h>

#define SCREEN_WIDTH 128
#define SCREEN_HEIGHT 64
#define OLED_RESET    -1
Adafruit_SSD1306 display(SCREEN_WIDTH, SCREEN_HEIGHT, &Wire, OLED_RESET);

// ── Motor pins ───────────────────────────────────────────
const uint8_t leftMotor[4]    = {8, 9, 10, 11};
const uint8_t rightMotor[4]   = {4, 5,  6,  7};
const uint8_t suctionMotor[4] = {2, 3, 12, 13};

// ── Buttons & LED ────────────────────────────────────────
#define BTN1    A0
#define BTN2    A1
#define BTN3    A2
#define RED_LED A3

// ── Mode flags ───────────────────────────────────────────
bool warmingOn = false;
bool suctionOn = false;
bool massageOn = false;

// ── Stepper half-step sequence ───────────────────────────
const uint8_t stepSeq[8] = {
  0b0001, 0b0011, 0b0010, 0b0110,
  0b0100, 0b1100, 0b1000, 0b1001
};
uint8_t stepIdx[3] = {0, 0, 0}; // [0]=left [1]=right [2]=suction

// ── Step timing ──────────────────────────────────────────
// 28BYJ-48 needs ~2-15ms per step to physically move
// 8ms gives smooth rotation with good torque — tune if needed
#define MASSAGE_STEP_MS  1    // chest motors step interval
#define SUCTION_STEP_MS  1    // suction motor step interval
unsigned long lastMassageStep = 0;
unsigned long lastSuctionStep = 0;

// ── Simulated temperature ────────────────────────────────
float simTemp = 36.8;
unsigned long lastTempTick = 0;

// ── Debounce ─────────────────────────────────────────────
#define DEBOUNCE_MS 300
unsigned long lastPress[3] = {0, 0, 0};

// ── Motor helpers ────────────────────────────────────────
void stepMotor(const uint8_t pins[4], uint8_t &idx) {
  uint8_t s = stepSeq[idx];
  for (uint8_t i = 0; i < 4; i++)
    digitalWrite(pins[i], (s >> i) & 1);
  idx = (idx + 1) % 8;
}

void stopMotor(const uint8_t pins[4]) {
  for (uint8_t i = 0; i < 4; i++)
    digitalWrite(pins[i], LOW);
}

// ── Button helper ────────────────────────────────────────
bool btnPressed(uint8_t pin, uint8_t idx) {
  if (digitalRead(pin) == LOW) {
    unsigned long now = millis();
    if (now - lastPress[idx] > DEBOUNCE_MS) {
      lastPress[idx] = now;
      while (digitalRead(pin) == LOW); // wait for release
      delay(20);
      return true;
    }
  }
  return false;
}

// ── Draw home screen ─────────────────────────────────────
void drawHome() {
  display.clearDisplay();
  display.setTextColor(SSD1306_WHITE);

  if (warmingOn) {
    display.setTextSize(1);
    display.setCursor(0, 0);
    display.print(F("Temp: "));
    display.print(simTemp, 1);
    display.print(F("C "));
    if      (simTemp < 36.0) display.print(F("! LOW"));
    else if (simTemp > 37.5) display.print(F("! HIGH"));
    else                     display.print(F("OK"));
    display.drawLine(0, 11, 127, 11, SSD1306_WHITE);
  }

  uint8_t y = warmingOn ? 14 : 2;
  display.setTextSize(1);

  display.setCursor(0, y);
  display.print(warmingOn ? F("> [WARMING ON]  ") : F("  1: Warming    "));

  display.setCursor(0, y + 12);
  display.print(suctionOn ? F("> [SUCTION ON]  ") : F("  2: Suction    "));

  display.setCursor(0, y + 24);
  display.print(massageOn ? F("> [MASSAGE ON]  ") : F("  3: Massage    "));

  uint8_t divY = warmingOn ? 54 : 44;
  display.drawLine(0, divY, 127, divY, SSD1306_WHITE);
  display.setCursor(0, divY + 3);
  display.print(F("B1=Warm B2=Suct B3=Msg"));

  display.display();
}

// ── Setup ────────────────────────────────────────────────
void setup() {
  // Init motor pins LOW
  for (uint8_t i = 0; i < 4; i++) {
    pinMode(leftMotor[i],    OUTPUT); digitalWrite(leftMotor[i],    LOW);
    pinMode(rightMotor[i],   OUTPUT); digitalWrite(rightMotor[i],   LOW);
    pinMode(suctionMotor[i], OUTPUT); digitalWrite(suctionMotor[i], LOW);
  }

  // Buttons with pullup
  pinMode(BTN1, INPUT_PULLUP);
  pinMode(BTN2, INPUT_PULLUP);
  pinMode(BTN3, INPUT_PULLUP);
  delay(100); // let pullups charge

  // LED
  pinMode(RED_LED, OUTPUT);
  digitalWrite(RED_LED, LOW);

  // OLED init
  display.begin(SSD1306_SWITCHCAPVCC, 0x3C);
  display.clearDisplay();

  // Splash screen
  display.setTextSize(2);
  display.setTextColor(SSD1306_WHITE);
  display.setCursor(15, 14);
  display.print(F("THE NERS"));
  display.setTextSize(1);
  display.setCursor(12, 40);
  display.print(F("Neonatal Response"));
  display.setCursor(22, 52);
  display.print(F("Swaddle v1.0"));
  display.display();
  delay(5000);

  // Seed timers AFTER splash
  unsigned long t = millis();
  lastPress[0] = lastPress[1] = lastPress[2] = t;
  lastTempTick      = t;
  lastMassageStep   = t;
  lastSuctionStep   = t;

  drawHome();
}

// ── Loop ─────────────────────────────────────────────────
void loop() {
  unsigned long now = millis();

  // ── Button 1: Warming toggle ──────────────────────────
  if (btnPressed(BTN1, 0)) {
    warmingOn = !warmingOn;
    digitalWrite(RED_LED, warmingOn ? HIGH : LOW);
    if (warmingOn) {
      display.clearDisplay();
      display.setTextSize(2);
      display.setTextColor(SSD1306_WHITE);
      display.setCursor(8, 10);
      display.print(F("Baby"));
      display.setCursor(8, 34);
      display.print(F("Warming"));
      display.display();
      delay(3000);
      lastTempTick = millis();
    }
    drawHome();
  }

  // ── Button 2: Suction toggle ──────────────────────────
  if (btnPressed(BTN2, 1)) {
    suctionOn = !suctionOn;
    if (!suctionOn) stopMotor(suctionMotor);
    drawHome();
  }

  // ── Button 3: Massage toggle ──────────────────────────
  if (btnPressed(BTN3, 2)) {
    massageOn = !massageOn;
    if (!massageOn) {
      stopMotor(leftMotor);
      stopMotor(rightMotor);
    }
    drawHome();
  }

  // ── Timed motor stepping ──────────────────────────────

  // Suction motor — step every SUCTION_STEP_MS
  if (suctionOn && now - lastSuctionStep >= SUCTION_STEP_MS) {
    lastSuctionStep = now;
    stepMotor(suctionMotor, stepIdx[2]);
  }

  // Chest massage motors — step every MASSAGE_STEP_MS
  if (massageOn && now - lastMassageStep >= MASSAGE_STEP_MS) {
    lastMassageStep = now;
    stepMotor(leftMotor,  stepIdx[0]);
    stepMotor(rightMotor, stepIdx[1]);
  }

  // ── Temperature simulation every 4s ──────────────────
  if (warmingOn && now - lastTempTick > 4000) {
    lastTempTick = now;
    simTemp += (random(-3, 4)) * 0.1;
    simTemp = constrain(simTemp, 35.5, 38.2);
    drawHome();
  }
}

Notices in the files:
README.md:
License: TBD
